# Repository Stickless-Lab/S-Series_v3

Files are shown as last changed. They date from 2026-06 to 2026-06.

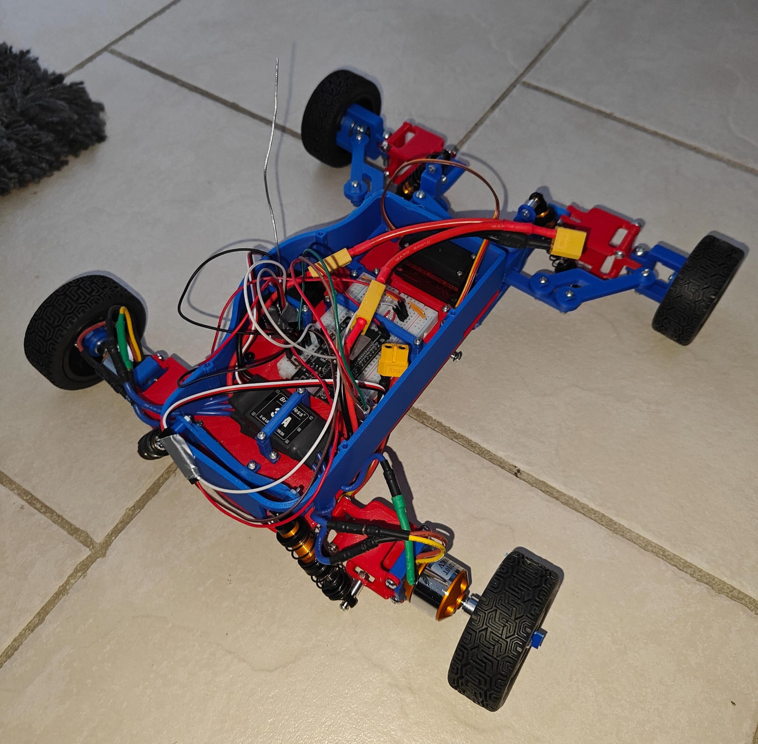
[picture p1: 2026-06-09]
images/BackImage.jpeg

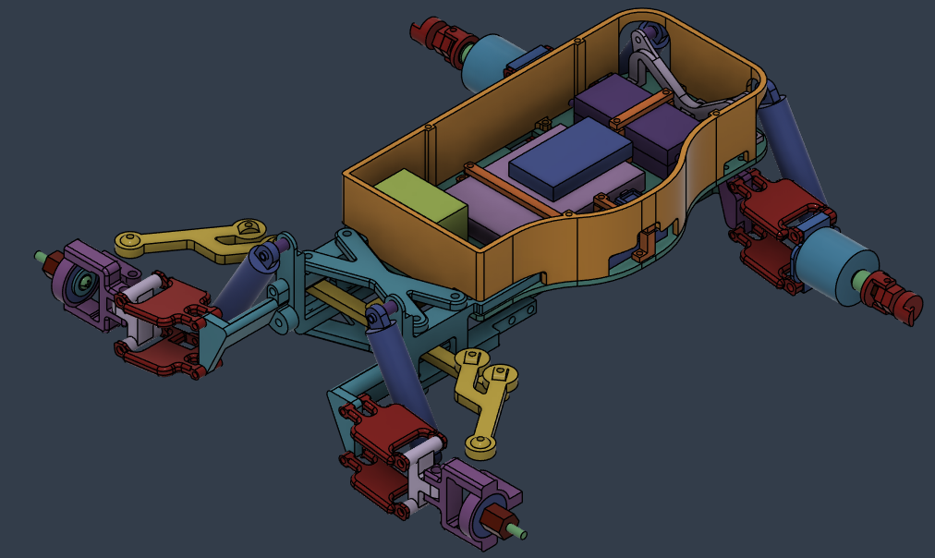
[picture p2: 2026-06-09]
images/CAD-Image3.png

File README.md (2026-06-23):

# S-Series_v3

This project is an Rc-Car. It is my 9th Rc-Car to be exact, but the 6th one when you exclude the ones I never finished.

## Why I Made This (and a little bit of history)

Even tho I never cared for rc cars this project line still has a special place in my heart. That's because the first, real project I've ever made was an rc car. It was a really bad one, it didn't even have a function to steer, but that all changed on the second version, where I introduced steering. For the 5th version I made a much better steering system and fixed the many flaws of the 2nd version. The 6th version was a failed experiment, it was meant to be a front wheel drive with thinner parts and custom wheel. Honestly the idea wasn't bad but the wheels had no grip and kind of made the whole project unusable. The 7th version was the first version with suspension, even tho it was very experimental and the suspension didn't work properly it was still much more stable and ridged than the older version. Now the 9th version and it's even more stable and the suspension actually works. This is the first version I'll feel comfortable driving for longer periods.

### Full Assembly






### Wiring

circuit_image

## Files

* `pcb/` - Wiring setup, no actual PCB
* `cad/` - CAD source files, STEP files, and STL files
* `firmware/` - Firmware source code
* `BOM.csv` - Bill of materials
* `assembly_instructions.md` - Instructions on how to assemble the car
* `images/` - Pretty self explanatory

## Bill of Materials

The full bill of materials is in [`bom.csv`](BOM.csv).

## License

This project is licensed under the Solderpad Hardware License v2.1.

SPDX-License-Identifier: Apache-2.0 WITH SHL-2.1

This license applies to the full project.

See the [LICENSE](LICENSE) file for details.

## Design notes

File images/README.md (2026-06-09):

# Images

This folder contains the images used to document the S-Series V3 project.

## What is included

* full circuit image
* CAD screenshots
* photos of the physical build

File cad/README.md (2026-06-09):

# CAD

This folder contains the CAD files for the S-Series V3 hardware design.

## What is included

* 3D model files for the project parts
* exported STEP files so the design can be viewed without the original CAD software
* STL files for all 3D printed parts
* f3d files so you can edit them in fusion

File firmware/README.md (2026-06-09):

# Firmware

This folder contains the firmware for the S-Series V3 controller.

The firmware runs on an ESP32 and reads RC receiver input signals for steering and throttle. It then sends control signals to two ESCs and one steering servo.

## Required library

This firmware uses the `ESP32Servo` library.

Install it in the Arduino IDE:

1. Open Arduino IDE
2. Go to **Sketch -> Include Library -> Manage Libraries**
3. Search for `ESP32Servo`
4. Install the library

## Uploading the firmware

1. Open the firmware file in Arduino IDE.
2. Select the ESP32 Dev Module.
3. Select the correct USB port.
4. Install the `ESP32Servo` library if it is not already installed.
5. Click **Upload**.

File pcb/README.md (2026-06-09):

## Circuit

This project does not use a custom PCB. Instead, the circuit is documented with:

* an image of the full circuit
* a wiring table showing every connection
* a Cirkit Designer link to the complete circuit design

**Cirkit Designer link:** [Cirkit](https://app.cirkitdesigner.com/project/98a8d149-222e-4ded-919d-9952a3b7c41c)

---

## Wiring Table

| From | To |
| --- | --- |
| **ESC 1 5V power supply** | **ESP32 VIN** |
| **ESC 1 ground** | **ESP32 GND** |
| **ESC 2 5V power supply** | **Receiver CH1 +** |
| **ESC 2 ground** | **Receiver CH1 - / GND** |
| **Receiver CH2 +** | **Servo positive** |
| **Receiver CH2 - / GND**  | **Servo negative** |
| **Receiver GND** | **ESP32 GND** |
| **Receiver CH1 signal** | **ESP32 D32** |
| **Receiver CH2 signal** | **ESP32 D33** |
| **ESP32 D21** | **Servo signal wire** |
| **ESP32 D18** | **ESC 1 signal wire** |
| **ESP32 D19** | **ESC 2 signal wire** |
| **Main battery +** | **ESC 1 positive power cable** |
| **Main battery -** | **ESC 1 negative power cable** |
| **Main battery +** | **ESC 2 positive power cable** |
| **Main battery -** | **ESC 2 negative power cable** |

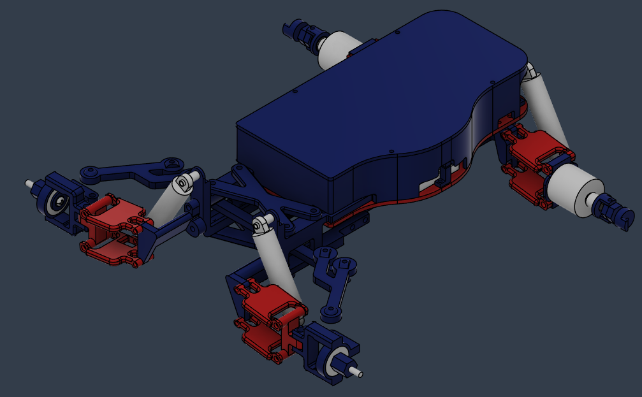
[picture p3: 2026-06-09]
images/CAD-Image1.png

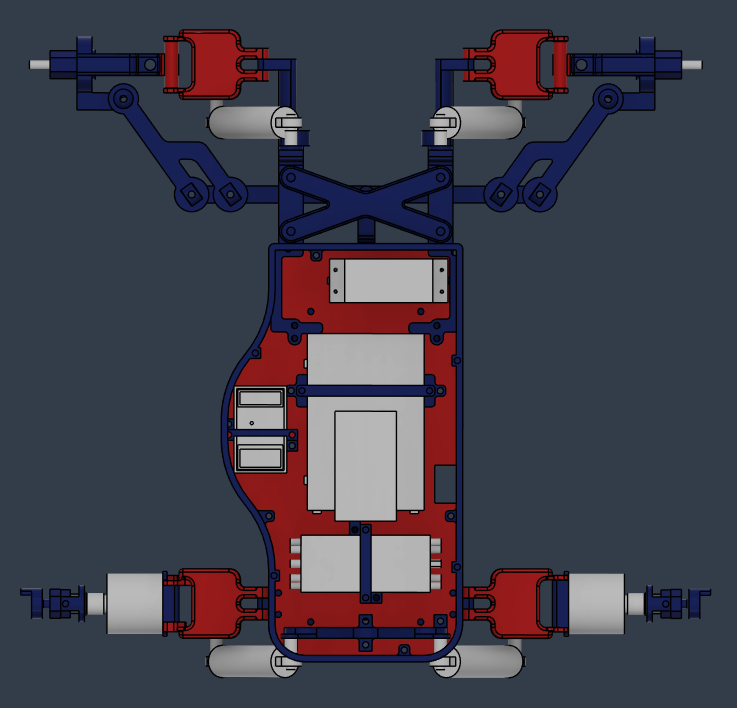
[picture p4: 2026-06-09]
images/CAD-Image2.png

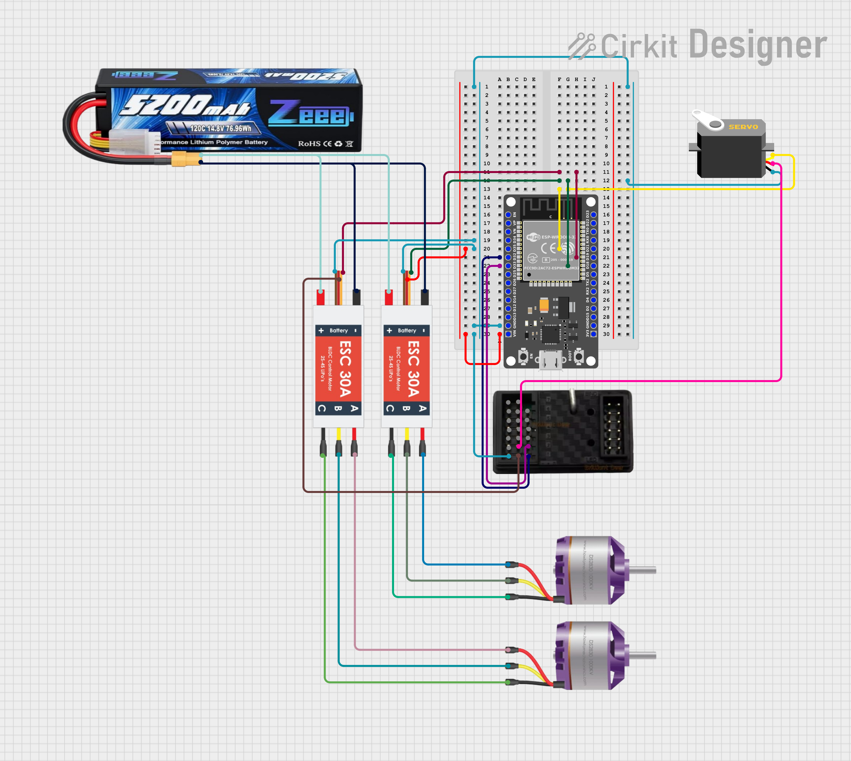
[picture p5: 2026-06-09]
images/circuit_image.png

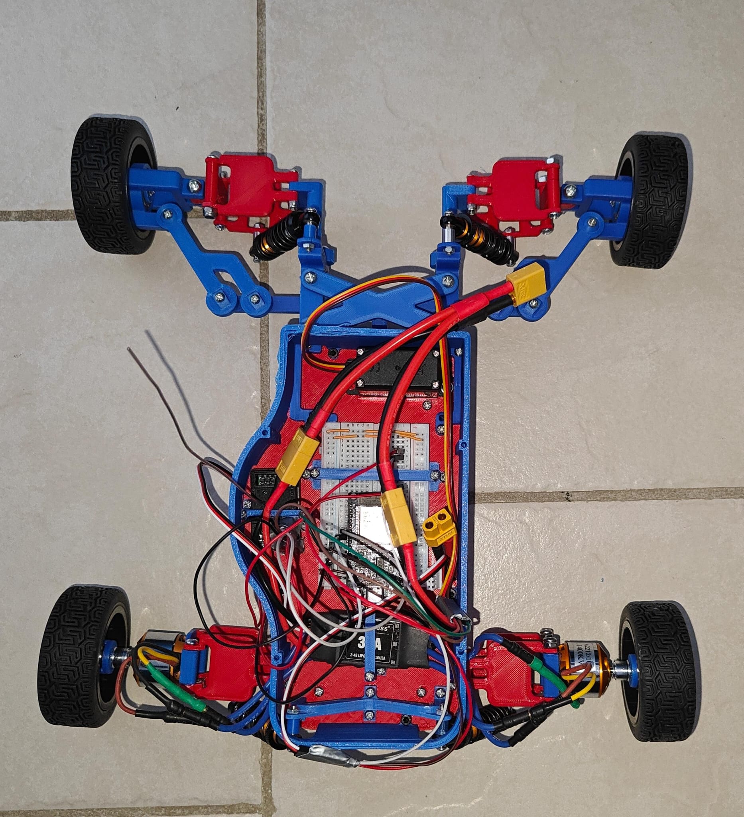
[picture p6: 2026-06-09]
images/BirdseyeImage.jpeg

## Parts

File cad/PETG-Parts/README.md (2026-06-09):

## 3D Printing Instructions

Print all parts in **PETG**.

* Check the part orientation before printing. Some orientations might be stronger.
* Add supports when needed.

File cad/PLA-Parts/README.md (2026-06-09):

## 3D Printing Instructions

Print all parts in **PLA**.

Most parts can be sliced and printed normally. Use your slicer's default PLA settings unless a specific part needs extra strength or support.

## Ball Joint Parts

When importing the ball joint files into your slicer, select the following files together:

* Connector
* Ball
* Ball2
* Sphere

When the slicer asks:

> Load these files as a single object with multiple parts?

Select **Yes**.

This keeps the ball joint parts aligned correctly for printing.

## Notes

* Check the part orientation before printing. Some orientations might be stronger.
* Add supports when needed.
* Make sure all ball joint pieces stay in their correct positions when loaded.

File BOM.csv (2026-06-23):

Item | Supplier | Price | URL
2x Outrunner Motor | Amazon (BE) | 2x €14.72 | https://www.amazon.com.be/professionele-borstelloze-upgrade-onderdelen-compatibel-quadcopter/dp/B08GFGYTWG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
Turnigy LiPo Battery 3000mAh 3S 20C (XT60) | HobbyKing | €15.88 | https://hobbyking.com/en_us/turnigy-battery-3000mah-3s-20c-lipo-pack-xt-60.html?___store=en_us
2x ESC | Amazon (BE) | 2x €8.99 | https://www.amazon.com.be/-/nl/gp/product/B0CK279BV1/ref=ox_sc_act_image_2?smid=A2D3HAWPO6HEDQ&psc=1
Wheel Tires | Aliexpress | €11.89 | https://nl.aliexpress.com/item/1005006259281273.html
Receiver and Transmitter | Aliexpress | €18.29 | https://nl.aliexpress.com/item/1005007146903164.html
Shockabsorbers [70mm] | Aliexpress | €13.39 | https://nl.aliexpress.com/item/1005005791841993.html
Half Breadboard | Aliexpress | €3.59 | https://nl.aliexpress.com/item/1005003647931024.html
Bearings | Aliexpress | €4.32 | https://nl.aliexpress.com/item/1005005511187974.html?utparam-url=scene%3Asearch%7Cquery_from%3A
XT60 Cable Splitter | Aliexpress | €3.16 | https://nl.aliexpress.com/item/1005006856749915.html
ESP32 NodeMCU (ESP-WROOM-32) Dev Board | Amazon (BE) | €6.00 | https://nl.aliexpress.com/item/1005008503831020.html
Miuzei Servo 15kg 5V | Amazon (BE) | €14.99 | https://www.amazon.com.be/-/en/Digital-Gearbox-Airplane-Standard-Building/dp/B0C1TXW74L
Hex Nylon Insert Nuts | Aliexpress | €9.99 | https://nl.aliexpress.com/item/1005008473715278.html
Total |  | €138.93

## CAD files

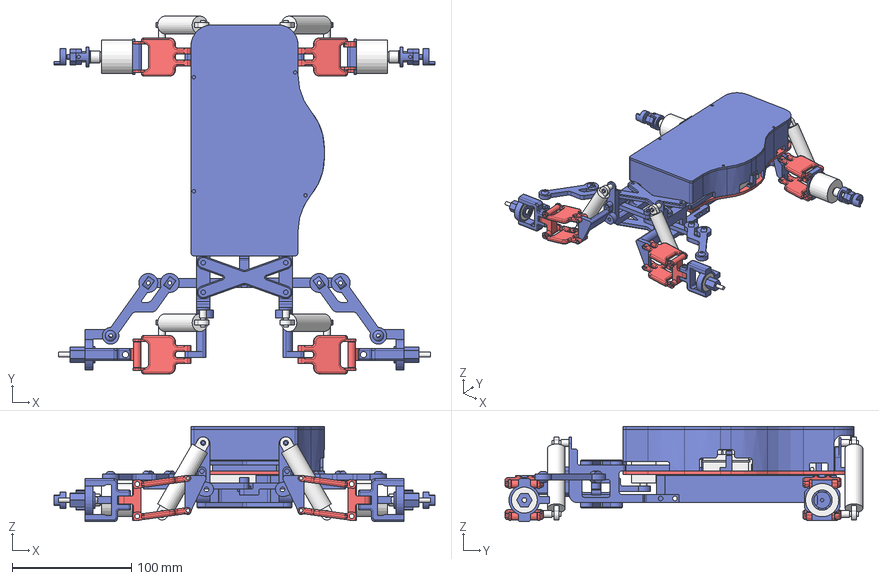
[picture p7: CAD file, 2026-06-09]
cad/full-assembly.step
319.9 x 300.3 x 79.9 mm
BatteryHolder
Holders
BackArms
BackMotorHolder
BackArmsConnector
BackSuspensionHolder
Servo
FrontLink
BallJoint
BearingHolder
FrontArms
SuspensionCoupler
FrontSuspensionHolder
Roof
Breadboard
Esc
Esp32
Motor
Suspension
Receiver
MotorHolderScrews
SuspensionSpacer
MotorWheelMount
Bearings
BearingWheelMount
M4x30mm
MotorWheelCoupler
M5-Nut
BearingWheelCoupler

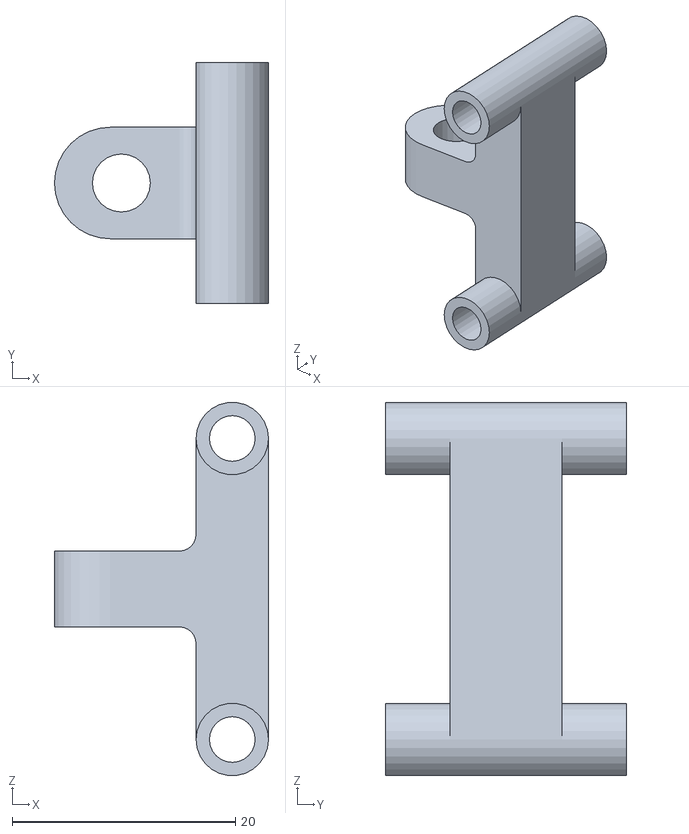
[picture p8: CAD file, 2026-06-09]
cad/PETG-Parts/RightAxisTurn.stl
19.2 x 21.6 x 33.5

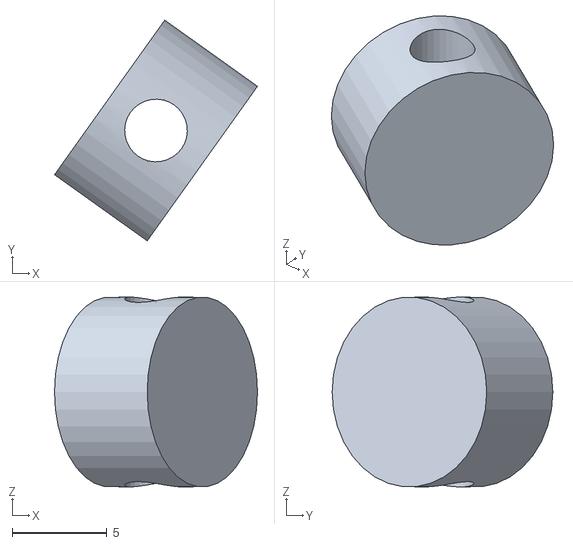
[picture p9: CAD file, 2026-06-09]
cad/PLA-Parts/Ball.stl
10.7 x 11.6 x 10.0

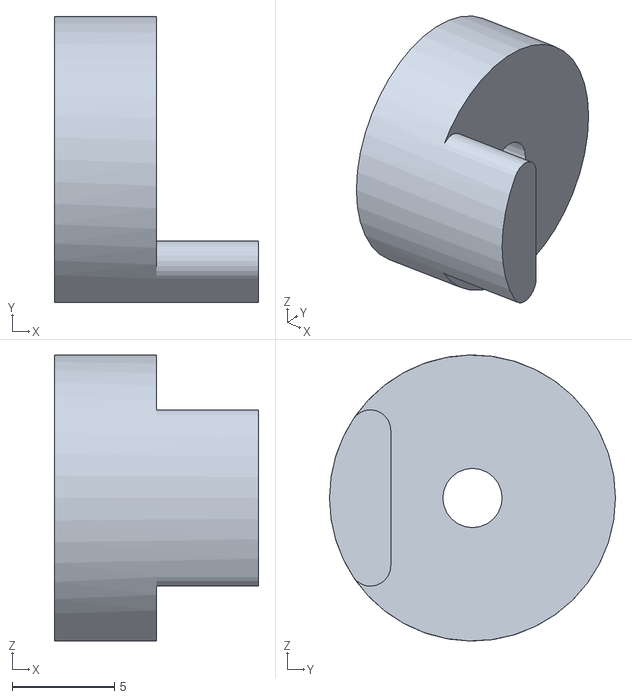
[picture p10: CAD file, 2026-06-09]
cad/PLA-Parts/Part3_Left.stl
10.0 x 14.0 x 14.0

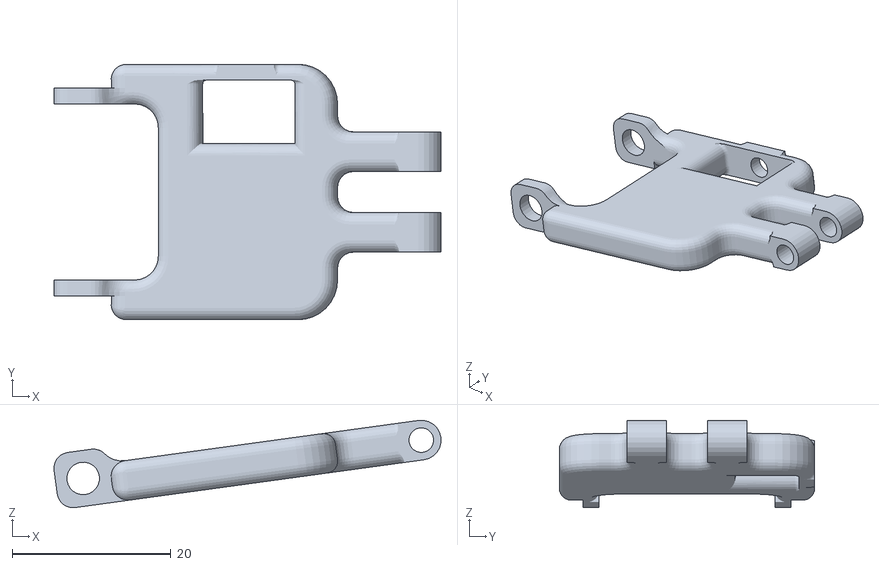
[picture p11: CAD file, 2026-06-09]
cad/PETG-Parts/BottomRighBacktArm.stl
48.7 x 32.1 x 11.0

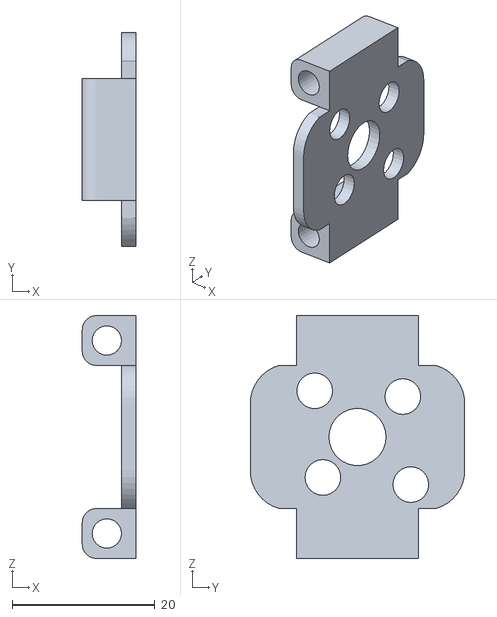
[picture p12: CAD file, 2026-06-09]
cad/PLA-Parts/MotorHolderLeft.stl
7.50 x 30.0 x 34.0

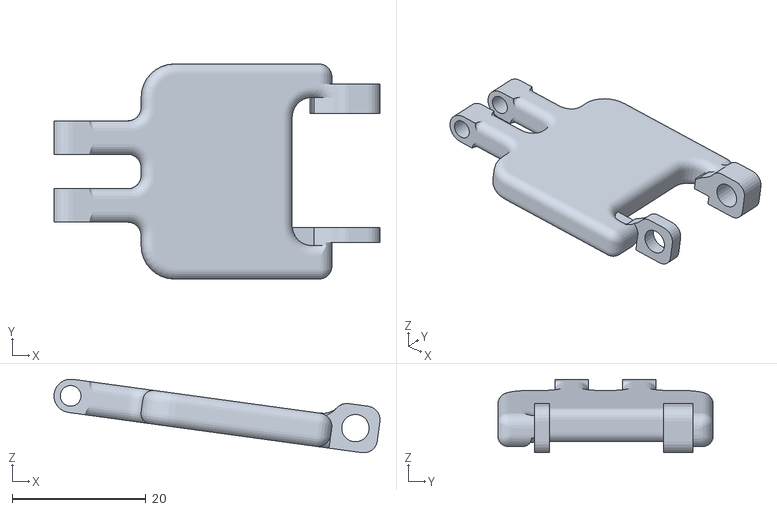
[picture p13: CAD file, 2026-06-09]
cad/PETG-Parts/TopBackLeftArm.stl
48.7 x 32.1 x 11.0

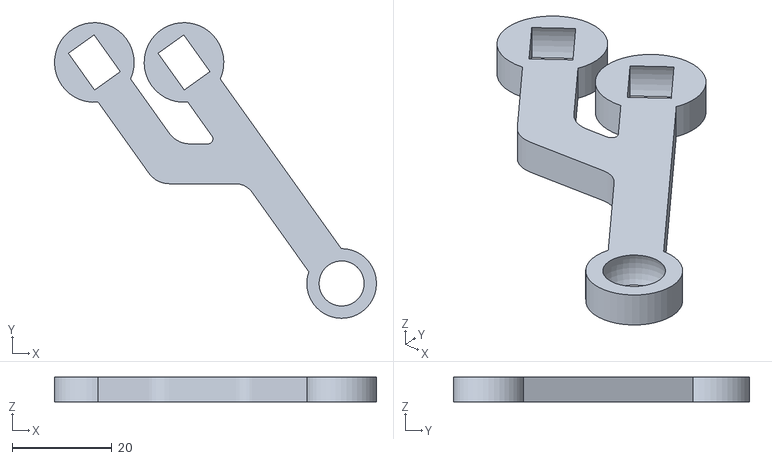
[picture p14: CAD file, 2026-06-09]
cad/PLA-Parts/Connector_L.stl
64.6 x 59.4 x 5.00

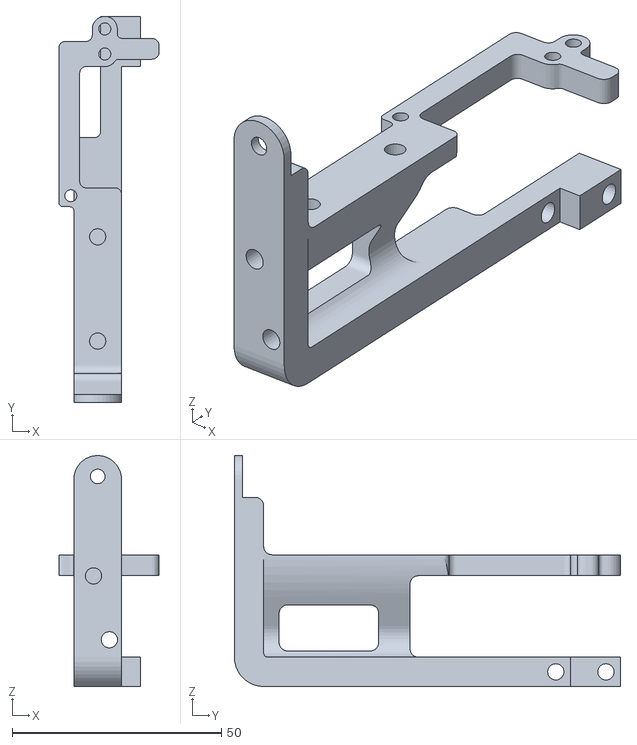
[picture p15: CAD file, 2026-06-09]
cad/PLA-Parts/SuspensionHolder_Right.stl
24.0 x 92.4 x 55.2

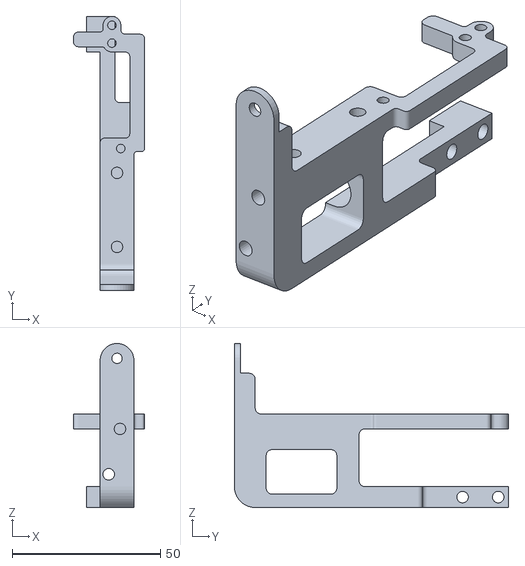
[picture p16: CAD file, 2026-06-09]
cad/PLA-Parts/SuspensionHolder_Left.stl
24.0 x 92.4 x 55.2

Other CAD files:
cad/PETG-Parts/LeftAxisTurn.stl
cad/PLA-Parts/Ball_L.stl
cad/PETG-Parts/TopFrontRightArm.stl
cad/PETG-Parts/BottomLeftFrontArm.stl
cad/PETG-Parts/TopRightArm.stl
cad/PETG-Parts/TopLeftFrontArm.stl
cad/PLA-Parts/Ball2_L.stl
cad/PETG-Parts/BottomLeftArm.stl
cad/PETG-Parts/BatteryCap.stl
cad/PETG-Parts/BottomRightArm.stl
cad/PLA-Parts/ArmsMovers_Left.stl
cad/PLA-Parts/ArmsMovers_Right.stl
cad/PLA-Parts/Ball2.stl
cad/PLA-Parts/BatteryHolder.stl
cad/PLA-Parts/BottomCross.stl
cad/PLA-Parts/Connector.stl
cad/PLA-Parts/FrontLeftWheelMount.stl
cad/PLA-Parts/L_Breadboard.stl
cad/PLA-Parts/L_Link.stl
cad/PLA-Parts/LeftBackSuspensionArmHolder.stl
cad/PLA-Parts/LeftBearingHolder.stl
cad/PLA-Parts/LeftScrewHolder_Bearing.stl
cad/PLA-Parts/MotorHolderRight.stl
cad/PLA-Parts/PB_EscHolder.stl
cad/PLA-Parts/PB_ReceiverHolder.stl
cad/PLA-Parts/PF_EscHolder.stl
cad/PLA-Parts/PF_ReceiverHolder.stl
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

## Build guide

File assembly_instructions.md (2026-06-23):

# Assembly Instructions

This is not a full step-by-step guide on how to assemble the car. I will explain the main things you need to do, and you should be able to figure out most of it as you go. It is honestly not that hard.

I highly recommend downloading the Fusion assembly file [here](cad/S-Series_v3.4.78.f3z) and opening it in Fusion, which is free to use. This file shows the full assembly, so you can clearly see where every part needs to go.

## Purchase the items

Make sure you have all the required items before starting the build. Everything needed for this project can be found in the [BOM.csv](BOM.csv).

You will also need a screw kit with screws ranging from M3 to M5, and lengths from around 6 mm to 40 mm. I do not have an exact screw count for this project, but a kit similar to [this one](https://www.amazon.com.be/-/nl/KOXXIAMOQ-verzonken-schroeven-moeren-sluitringen/dp/B0CJ6LCV9W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) should be good. I apologize for that and the next project I'll make will have that. For screws that might come lose use the Hex Nylon Insert Nuts you bought.

## 3D print the parts

Next, 3D print all the required parts.

Print the parts in [PLA-Parts](cad/PLA-Parts) using PLA.

Print the parts in [PETG-Parts](cad/PETG-Parts) using PETG.

When you open the `.f3z` file mentioned earlier, the PLA parts are shown in blue and the PETG parts are shown in red.

## Assembly

Once you have all the printed parts, bought components, and screws in front of you, open the `.f3z` file and use it as a reference for where everything goes.

There are no fixed instructions like “use this exact screw here and that exact screw there.” I apologize for that, but in most places you can just use the screw size and length that fits best. As long as the screw fits and holds the part properly, it should be fine.

For most parts, it also does not matter too much if the screw sticks out a little. I had that in a few places too.

Be careful when screwing parts onto the `BatteryHolder`. You do not want to puncture the battery. This is especially important for parts like:

* `SuspensionHolder-Left`
* `SuspensionHolder-Right`
* `PF-ReceiverHolder`
* `PB-ReceiverHolder`
* ...

I recommend screwing these parts into the `BatteryHolder` first, and only putting the battery inside after that.

In the Fusion assembly, the white parts are the bought components.

## Upload the Firmware

Upload the firmware to the ESP32 before finishing the wiring.

The firmware can be found here:

[firmware/S-Series-v3.cpp](https://github.com/Stickless-Lab/S-Series_v3/blob/main/firmware/S-Series-v3.cpp)

More detailed firmware upload instructions are available here:

[firmware/README.md](https://github.com/Stickless-Lab/S-Series_v3/blob/main/firmware/README.md)

## Wiring

After the firmware is uploaded, wire all the electronics together.

You do not need a soldering iron for this project. All wiring instructions can be found in this folder:

[pcb](https://github.com/Stickless-Lab/S-Series_v3/tree/main/pcb)

## Powering the Car On and Off

When turning the car on:

1. Turn on the transmitter first.
2. Connect the XT60 cable splitter to the battery so the car powers on.

When turning the car off:

1. Disconnect the XT60 cable splitter from the battery.
2. Turn off the transmitter.

After this, your car should be ready to use.

Thank you, and have fun driving!

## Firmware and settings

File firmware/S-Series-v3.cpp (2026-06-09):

#include <ESP32Servo.h>

const int RX_STEERING_PIN = 32;
const int RX_THROTTLE_PIN = 33;

const int ESC_1_PIN = 18;
const int ESC_2_PIN = 19;
const int SERVO_PIN = 21;

const int PWM_MIN = 1000;
const int PWM_CENTER = 1500;
const int PWM_MAX = 2000;

const int RX_VALID_MIN = 750;
const int RX_VALID_MAX = 2250;

const int THROTTLE_STOP_POINT = 1500;
const int THROTTLE_FULL_POINT = 2000;

const int ESC_STOP_US = 1000;
const int ESC_MAX_US = 1200;

const int ARM_TIME_MS = 3000;

bool REVERSE_STEERING = false;

bool NORMAL_CAR_MODE = true;

bool USE_SERVO_STEERING = true;

const unsigned long SIGNAL_TIMEOUT_US = 30000;

int currentEsc1 = ESC_STOP_US;
int currentEsc2 = ESC_STOP_US;

Servo esc1;
Servo esc2;
Servo steeringServo;

void setup() {
  Serial.begin(115200);
  delay(200);

  pinMode(RX_STEERING_PIN, INPUT);
  pinMode(RX_THROTTLE_PIN, INPUT);

  esc1.setPeriodHertz(50);
  esc2.setPeriodHertz(50);
  steeringServo.setPeriodHertz(50);

  esc1.attach(ESC_1_PIN, PWM_MIN, PWM_MAX);
  esc2.attach(ESC_2_PIN, PWM_MIN, PWM_MAX);
  steeringServo.attach(SERVO_PIN, PWM_MIN, PWM_MAX);

  currentEsc1 = ESC_STOP_US;
  currentEsc2 = ESC_STOP_US;
  writeBothEscs(currentEsc1, currentEsc2);

  steeringServo.writeMicroseconds(PWM_CENTER);

  armEscs();

  Serial.println("RC ESP32 controller ready");
}

void loop() {
  int steeringIn = readRcChannel(RX_STEERING_PIN);
  int throttleIn = readRcChannel(RX_THROTTLE_PIN);

  if (steeringIn == 0 || throttleIn == 0) {
    stopCar();
    Serial.println("Signal lost - failsafe");
    delay(20);
    return;
  }

  steeringIn = constrain(steeringIn, PWM_MIN, PWM_MAX);
  throttleIn = constrain(throttleIn, PWM_MIN, PWM_MAX);

  if (REVERSE_STEERING) {
    steeringIn = reversePulse(steeringIn);
  }

  if (USE_SERVO_STEERING) {
    steeringServo.writeMicroseconds(steeringIn);
  }

  int throttle = throttleToEsc(throttleIn);

  int steering = steeringIn - PWM_CENTER;

  int esc1Out;
  int esc2Out;

  if (NORMAL_CAR_MODE) {
    esc1Out = throttle;
    esc2Out = throttle;
  } else {
    esc1Out = throttle + steering;
    esc2Out = throttle - steering;
  }

  esc1Out = constrain(esc1Out, ESC_STOP_US, ESC_MAX_US);
  esc2Out = constrain(esc2Out, ESC_STOP_US, ESC_MAX_US);

  currentEsc1 = esc1Out;
  currentEsc2 = esc2Out;

  writeBothEscs(currentEsc1, currentEsc2);

  Serial.print("Steering: ");
  Serial.print(steeringIn);
  Serial.print(" | Throttle RX: ");
  Serial.print(throttleIn);
  Serial.print(" | ESC1: ");
  Serial.print(esc1Out);
  Serial.print(" | ESC2: ");
  Serial.println(esc2Out);

  delay(20);
}

int throttleToEsc(int throttleIn) {
  if (throttleIn <= THROTTLE_STOP_POINT) {
    return ESC_STOP_US;
  }

  if (throttleIn >= THROTTLE_FULL_POINT) {
    return ESC_MAX_US;
  }

  return map(
    throttleIn,
    THROTTLE_STOP_POINT,
    THROTTLE_FULL_POINT,
    ESC_STOP_US,
    ESC_MAX_US
  );
}

void armEscs() {
  Serial.println("Arming ESCs at stop throttle...");

  currentEsc1 = ESC_STOP_US;
  currentEsc2 = ESC_STOP_US;

  writeBothEscs(currentEsc1, currentEsc2);
  steeringServo.writeMicroseconds(PWM_CENTER);

  delay(ARM_TIME_MS);

  Serial.println("ESCs armed");
}

void writeBothEscs(int us1, int us2) {
  esc1.writeMicroseconds(us1);
  esc2.writeMicroseconds(us2);
}

int readRcChannel(int pin) {
  unsigned long pulse = pulseIn(pin, HIGH, SIGNAL_TIMEOUT_US);

  if (pulse == 0) {
    return 0;
  }

  if (pulse < RX_VALID_MIN || pulse > RX_VALID_MAX) {
    return 0;
  }

  if (pulse < PWM_MIN) {
    pulse = PWM_MIN;
  }

  if (pulse > PWM_MAX) {
    pulse = PWM_MAX;
  }

  return (int)pulse;
}

int reversePulse(int pulse) {
  return PWM_MIN + PWM_MAX - pulse;
}

void stopCar() {
  currentEsc1 = ESC_STOP_US;
  currentEsc2 = ESC_STOP_US;

  writeBothEscs(currentEsc1, currentEsc2);
  steeringServo.writeMicroseconds(PWM_CENTER);
}

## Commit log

2026-06-08 Change license to Solderpad Hardware License v2.1
    Updated the license from MIT to Solderpad Hardware License v2.1, incorporating specific terms and conditions related to rights and definitions.
2026-06-09 Add README for CAD folder with project details
2026-06-09 Add README for PLA parts printing instructions
2026-06-09 Create README.md with 3D printing instructions
    Added 3D printing instructions for PETG parts.
2026-06-09 Revise BOM reference and clean up README
    Updated BOM file reference and removed build instructions and firmware section.
2026-06-23 Add more images to README.md
    Added additional images to the Full Assembly section.
2026-06-23 Revise BOM.csv with new items and formatting
    Updated BOM.csv to add new items and adjust formatting.
    [BOM.csv]
2026-06-23 Add assembly instructions to README
    Added a new section for assembly instructions in the README.
